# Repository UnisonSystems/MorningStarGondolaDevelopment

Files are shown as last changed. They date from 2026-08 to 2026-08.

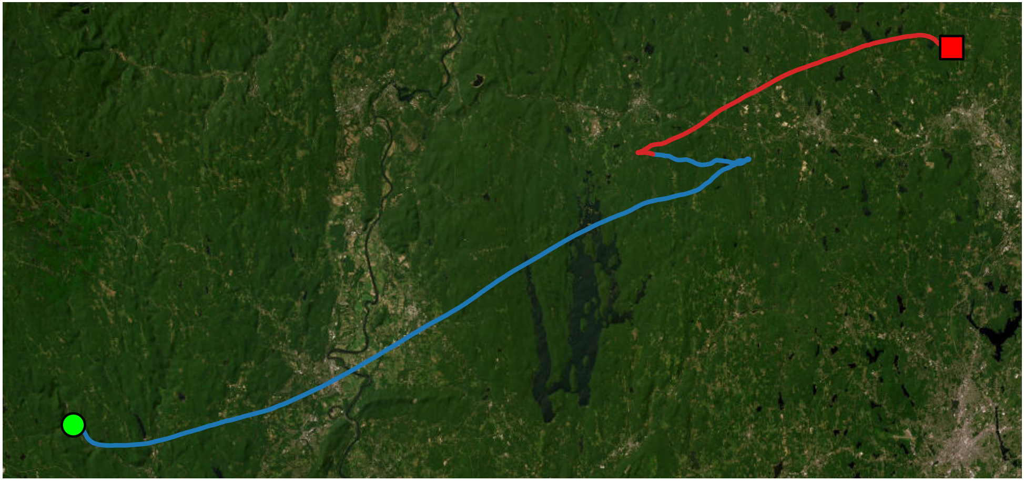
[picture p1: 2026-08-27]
Analysis/Flight/Report/trajectory_snapshot.png

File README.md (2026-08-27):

# Morning Star Gondola Development

Avionics, mechanical parts, bench tests, and post-flight analysis for the Morning Star high-altitude balloon gondola.

Current flight computer: Raspberry Pi Pico (RP2040) running the Earle Philhower Arduino-Pico core. Radio is a Tiny4FSK + Shield on a dedicated I2C bus. This repository does **not** contain Tiny4FSK firmware.

License: MIT (see `LICENSE`). Copyright 2026 Unison Systems.

## Layout

| Path | What it is |
|---|---|
| [`Flight-Software/`](Flight-Software/) | **Prototype Pico flight software.** Untested. Experiment with this. |
| [`Flight-Software-Heritage/`](Flight-Software-Heritage/) | MIT-Pico.ino flew in 2026. Also includes test scripts for novel sensors.|
| [`Benchtop-Testing/`](Benchtop-Testing/) | Single-sensor and combined Arduino sketches used to qualify hardware.|
| [`Analysis/`](Analysis/) | Python tools for flight logs and bench logs. Run generate_report.py on the cleaned flight log, DATALOG.CSV. Run test_main.ino to generate NNNN_flight_log.bin. Run bench_test_analysis.py with NNNN_flight_log.bin (try 0000_flight_log.bin as an example).|
| [`Hardware/`](Hardware/) | STL files for 3D-printed hardware. |

## Flight software

Source: [`Flight-Software/MIT-Pico/`](Flight-Software/MIT-Pico/).

Wiring and power: [`Flight-Software/pico_wiring.txt`](Flight-Software/pico_wiring.txt), [`Flight-Software/power_wiring.txt`](Flight-Software/power_wiring.txt).

| Item | Detail |
|---|---|
| Board | Raspberry Pi Pico |
| Core | Earle F. Philhower Arduino-Pico |
| Libraries | Adafruit BNO08x, Adafruit MAX31865, Adafruit SHT4x, Rob Tillaart MS5611, `SD` / `Wire` / `SPI` |
| On-board log | Packed binary records on MicroSD (`NNNN_flight_log.bin`) |
| Downlink | Pico is I2C peripheral `0x09` on GP2/GP3. Tiny4FSK is the controller and owns the 20 s packet cadence. |
| Run time | Until power loss or manual deactivation. GP10 MOSFET enable is asserted in `setup()` and held. |

Sensors logged to MicroSD:

- BNO086 at 100 Hz (SD only; not downlinked)
- MAX31865 + GY-63 MS5611 + SHT45 at 20 Hz
- XY-T01 #1 and #2 whenever a UART line parses (~1 Hz)

I2C snapshot to Tiny4FSK (16 bytes, little-endian): MAX temp, SHT45 temp, MS5611 temp, XY-T01 #1 temp, XY-T01 #2 temp, SHT45 RH, MS5611 pressure.

Open the `MIT-Pico` folder as an Arduino sketch (folder name must match `MIT-Pico.ino`). Build and flash with the Philhower Pico board package.

## Heritage firmware

[`Flight-Software-Heritage/`](Flight-Software-Heritage/) keeps the earlier payload software:

- `MIT-Onsite-Test/MIT-Pico` — Pico sketch from the CNT-era flight (LMP91000 array + Tiny4FSK slave)
- `MIT-Onsite-Test/i2c-scan` — I2C bus scanner
- `RaspPi Pico` / `RaspPi ZeroW` — MicroPython loggers from earlier gondola revisions

These are reference only. Pin maps and sensor lists do not match the current airframe.

## Bench tests

[`Benchtop-Testing/`](Benchtop-Testing/) is one sketch per check. Each `test_*` directory is its own Arduino sketch.

| Sketch | Purpose |
|---|---|
| `test_BNO086` | BNO086 on I2C0 |
| `test_GY63MS5611` | MS5611 |
| `test_MAX31865` | MAX31865 RTD |
| `test_SHT45` | SHT45 |
| `test_XYT01` | XY-T01 UART + heater commands |
| `test_MicroSD` | ADA254 card |
| `test_*_x_MicroSD` | That sensor plus SD logging |
| `test_main` | Combined logger used as the behavioral spec for current flight software |

## Analysis

- [`Analysis/Flight/`](Analysis/Flight/) — flight-log report generation (`generate-report.py`)
- [`Analysis/Testing/`](Analysis/Testing/) — bench-log helper (`bench_test_analysis.py`)

Use a virtualenv and the `requirements.txt` next to the flight script.

## Hardware

[`Hardware/`](Hardware/) is printable flight structure: Pico / sensor receivers, Tiny4FSK receivers, battery box, GoPro bay, switch housing, CNT cage (heritage), M3 washers.

## What this repo is not

- Not Tiny4FSK / Horus encoder source
- Not GoPro firmware
- Not a place to commit MicroSD flight binaries or USB-serial captures (see `.gitignore`)

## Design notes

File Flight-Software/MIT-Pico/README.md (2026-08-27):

# MIT-Pico

Board: Raspberry Pi Pico (RP2040)
Core: Earle F. Philhower Arduino-Pico

Libraries:
- Wire.h
- SPI.h
- SD.h
- Adafruit_BNO08x.h
- Adafruit_MAX31865.h
- Adafruit_SHT4x.h
- MS5611.h (Rob Tillaart)

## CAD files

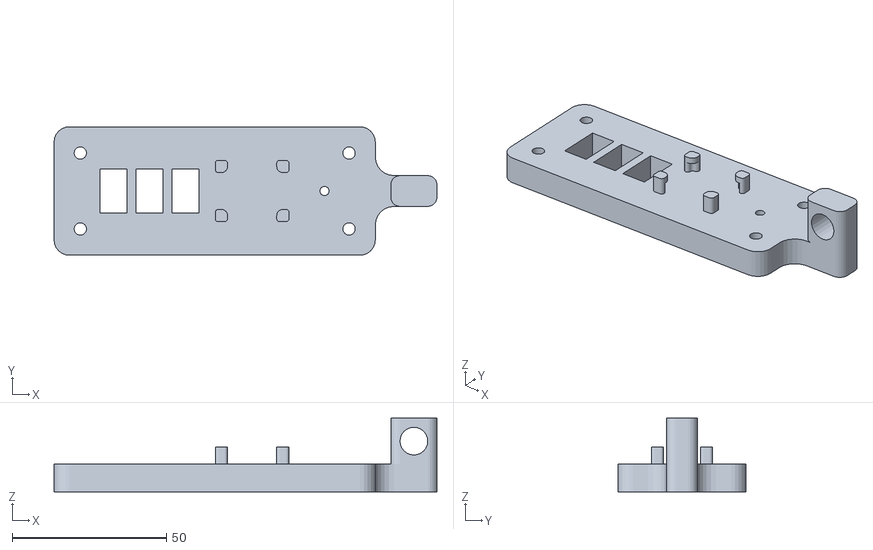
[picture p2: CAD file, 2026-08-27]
Hardware/switch_receiver.stl
124.3 x 41.7 x 24.0

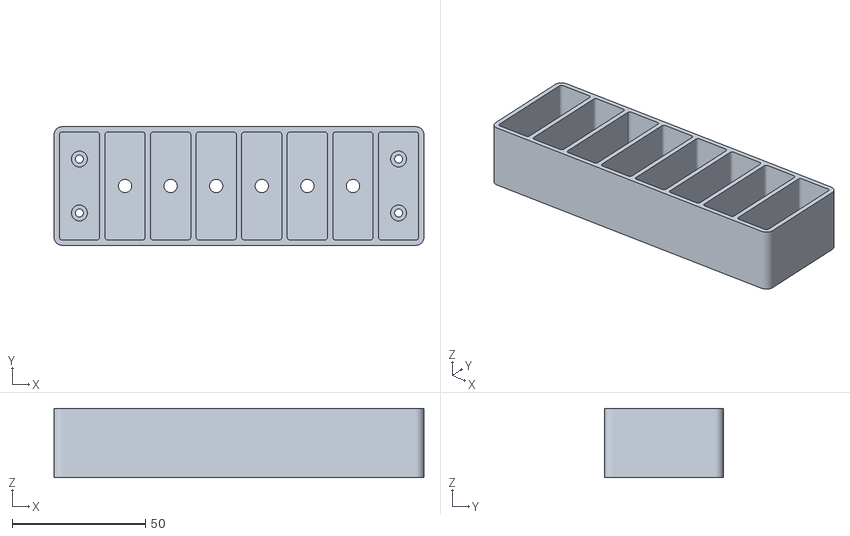
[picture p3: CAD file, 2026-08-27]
Hardware/Receiver_PCT-218.stl
138.8 x 44.5 x 26.0

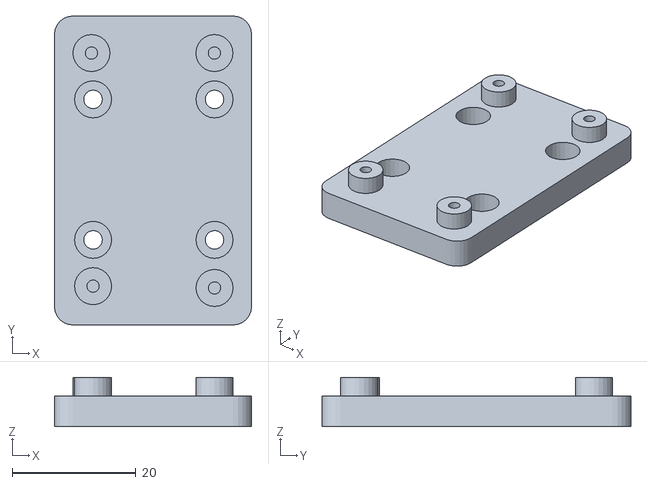
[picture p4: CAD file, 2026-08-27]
Hardware/Receiver_SD-Card.stl
31.9 x 50.0 x 8.00

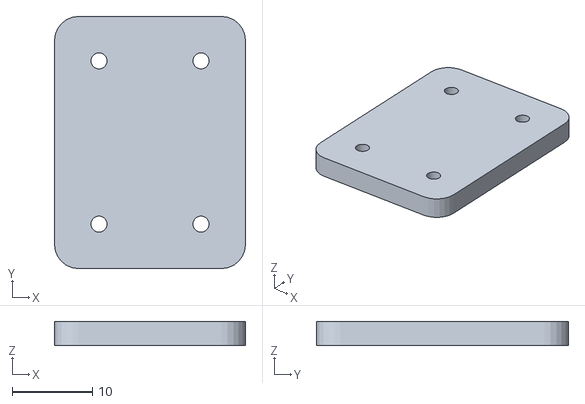
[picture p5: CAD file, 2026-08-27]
Hardware/Receiver_SHT45.stl
23.8 x 31.4 x 3.00

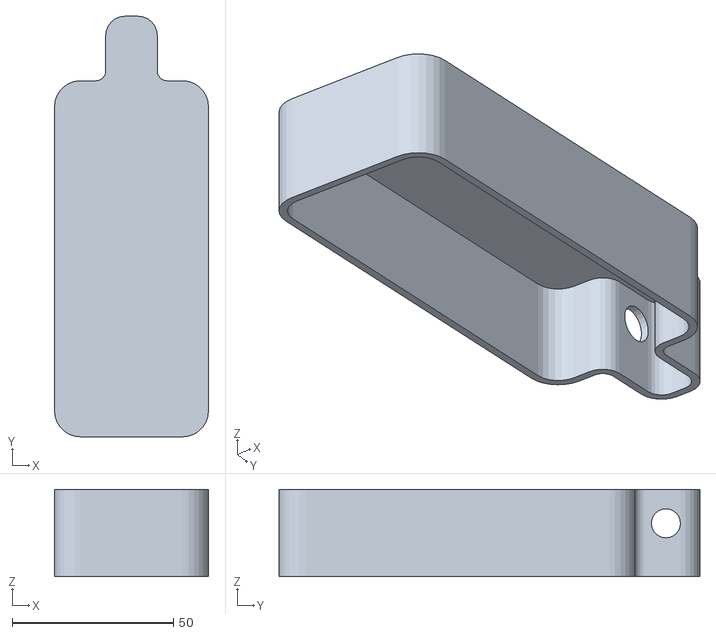
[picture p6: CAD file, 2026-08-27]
Hardware/switch_receiver_cover.stl
47.7 x 130.3 x 27.0

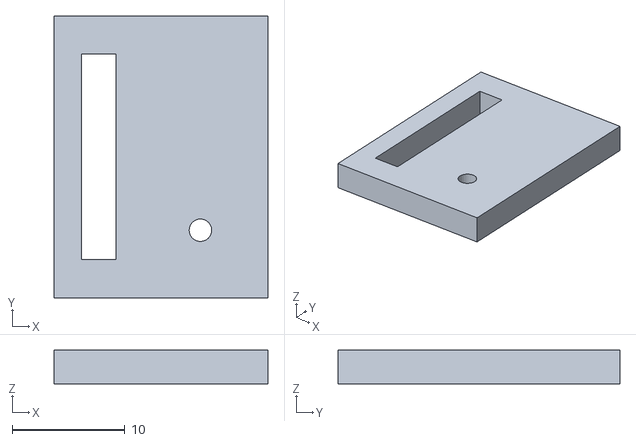
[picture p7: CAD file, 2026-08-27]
Hardware/Receiver_GY-63.stl
19.0 x 25.0 x 3.00

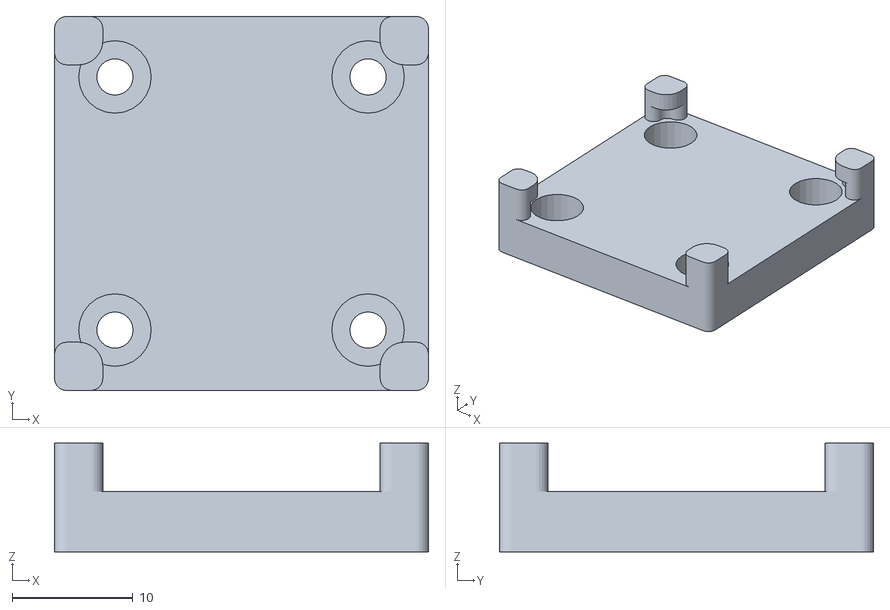
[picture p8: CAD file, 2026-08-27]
Hardware/Receiver_ICM-20948.stl
30.9 x 30.9 x 9.00

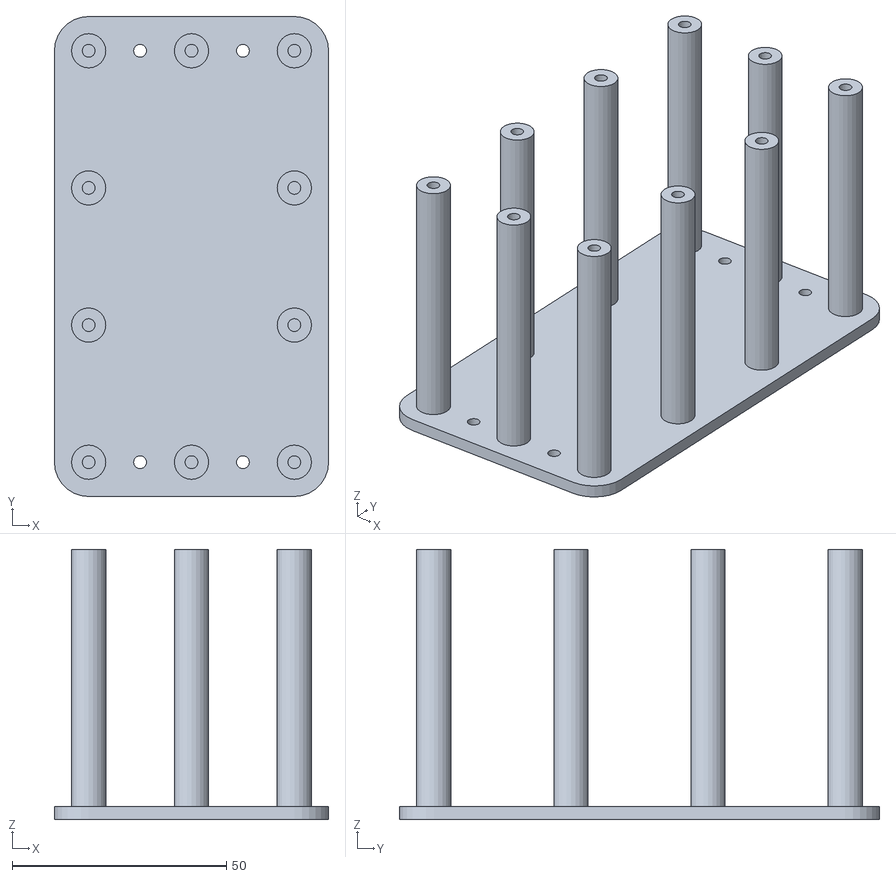
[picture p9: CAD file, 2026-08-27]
Hardware/CNT_electronics_cage.stl
64.0 x 112.0 x 63.0

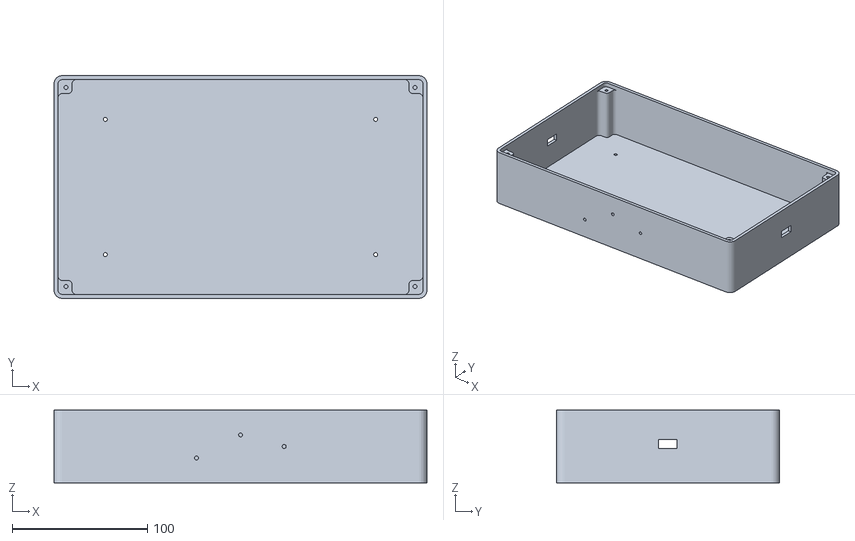
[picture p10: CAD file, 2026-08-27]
Hardware/battery_box.stl
275.8 x 164.8 x 53.8

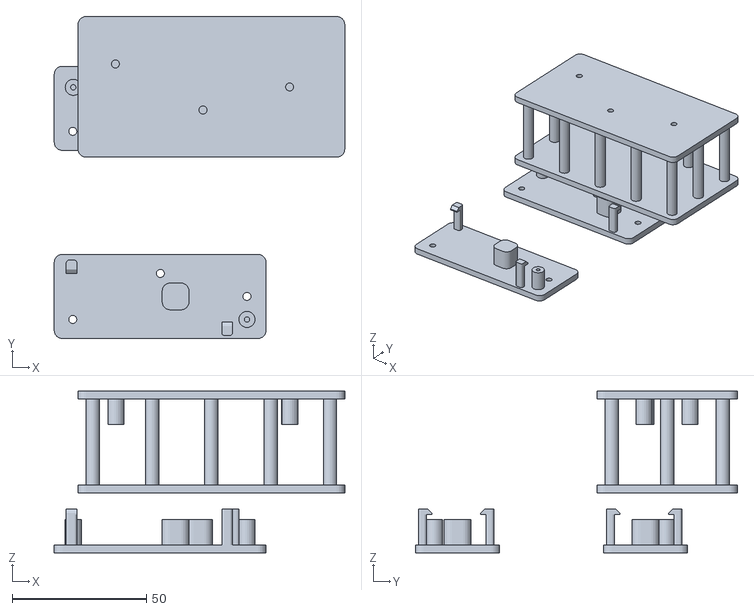
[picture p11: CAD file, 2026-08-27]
Hardware/Receivers_FSK.stl
108.1 x 119.8 x 60.3

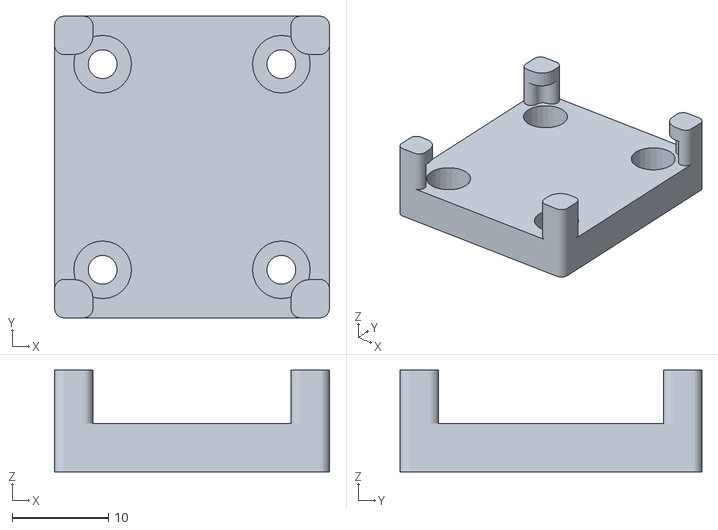
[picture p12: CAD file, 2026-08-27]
Hardware/Receiver_MAX31865.stl
28.6 x 31.4 x 10.6

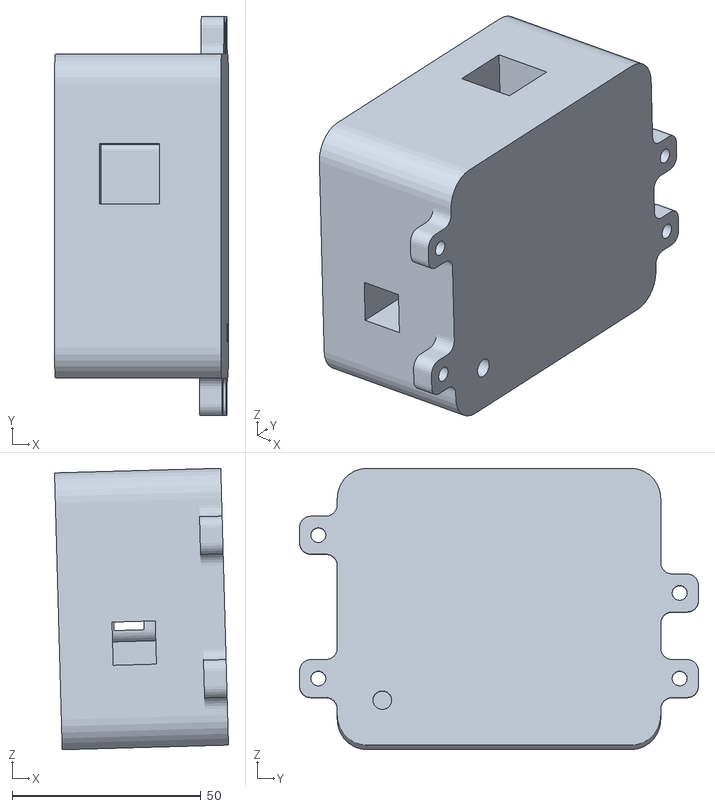
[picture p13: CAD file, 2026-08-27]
Hardware/GoPro_Bay.stl
46.1 x 105.8 x 74.6

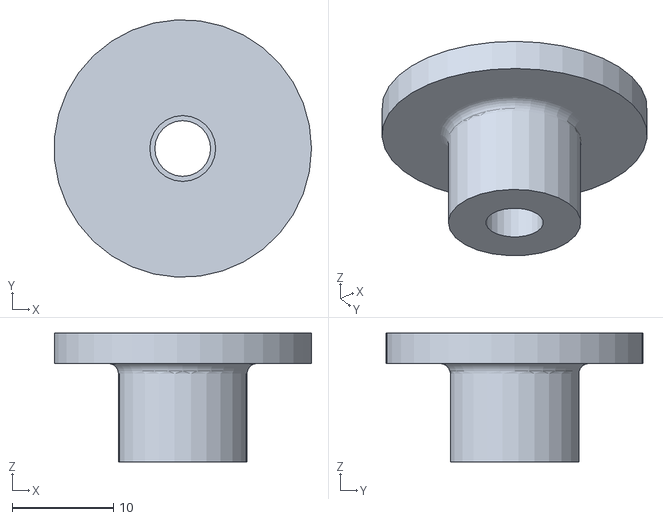
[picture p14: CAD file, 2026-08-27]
Hardware/Receiver_RTD.stl
25.3 x 25.4 x 12.7

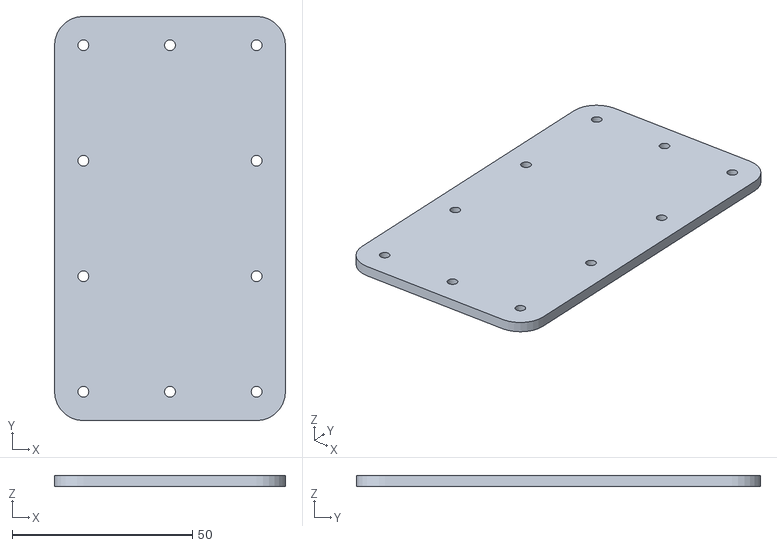
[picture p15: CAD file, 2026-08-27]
Hardware/CNT_electronics_cage_cover.stl
64.0 x 112.0 x 3.00

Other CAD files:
Hardware/Receiver_Pico.stl
Hardware/Receiver_HP.stl
Hardware/Receiver_XY-T01.stl
Hardware/Washer_M3.stl

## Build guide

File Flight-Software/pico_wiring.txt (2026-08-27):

| Pico Pin | Terminal Block | Function | Connected Devices |
|---|---|---|---|
| MicroUSB | — | Power input | Battery POSA (via rocker) + GND |
| VBUS | TB-5V | 5 V distribution rail | MS5611, MAX31865, MicroSD (ADA254), BSS138 HV, etc.  |
| GND | TB-GND | Common ground | All grounds, M_GPIO-, level shifter GND |
| 3V3(OUT) | TB-3V3 | 3.3 V rail | BNO086, SHT45, level shifter LV |
| GP0 (UART0 TX) | — | XY-T01 #1 TX (via LV) | BSS138 → XY-T01-1 RX |
| GP1 (UART0 RX) | — | XY-T01 #1 RX (via LV) | BSS138 → XY-T01-1 TX |
| GP2 (I2C1 SDA) | — | Tiny4FSK dedicated SDA | Shield SDA (Pico = slave 0x09) |
| GP3 (I2C1 SCL) | — | Tiny4FSK dedicated SCL | Shield SCL |
| GP4 (I2C0 SDA) | TB-SDA | Shared I2C SDA | MS5611, BNO086, SHT45 |
| GP5 (I2C0 SCL) | TB-SCL | Shared I2C SCL | MS5611, BNO086, SHT45 |
| GP6 | — | BNO086 INT | BNO086 INT (active-low) |
| GP7 | — | BNO086 RST | BNO086 RST (active-low) |
| GP8 (UART1 TX) | — | XY-T01 #2 TX (via LV) | BSS138 → XY-T01-2 RX |
| GP9 (UART1 RX) | — | XY-T01 #2 RX (via LV) | BSS138 → XY-T01-2 TX |
| GP10 | — | MOSFET control | M_GPIO+ |
| GP15 | – | Status indicator | LED |
| GP16 (SPI0 RX) | TB-MISO | SPI0 MISO | MAX31865 SDO, MicroSD (ADA254) MISO/DO |
| GP17 | — | MicroSD CS | MicroSD (ADA254) CS |
| GP18 (SPI0 SCK) | TB-SCK | SPI0 SCK | MAX31865 SCK, MicroSD (ADA254) SCK/CLK |
| GP19 (SPI0 TX) | TB-MOSI | SPI0 MOSI | MAX31865 SDI, MicroSD (ADA254) MOSI/DI |
| GP20 | — | MAX31865 CS | MAX31865 CS |

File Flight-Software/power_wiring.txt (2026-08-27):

Quick notes on notation:

I assign the names POS<A/B> and NEG<A/B> to the positive and negative lines of Outputs A/B.
The MOSFET has 4 screw terminals: M_IN+ (power supply positive line in); M_IN- (power supply negative line in); M_OUT+ (load positive line out); M_OUT- (load negative line out). The MOSFET has 2 GPIO pins: M_GPIO+ (the logic pin); and M_GPIO- (ground).
I refer to the ith terminal of terminal block receiving positive lines as T+<i>. I refer to the ith terminal of terminal block receiving negative lines as T-<i>.
I refer to an arbitrary lead of the ith FG26X7R1E106KRT00 as CAP_<i>A. I refer to other lead of the ith FG26X7R1E106KRT00 as CAP_<i>B.

The Battery supplies 5 V.

DD0324PW-1 and DD0324PW-2 output at 12 V.
 
Battery POSA connects directly to either rocker-switch terminal. Battery POSA (new wire) feeds out of the other rocker-switch terminal and connects to the MicroUSB port on the Pico. Battery NEGA connects directly to Pico GND.
 
Battery POSB connects directly to M_IN+. Battery NEGB connects directly to M_IN-. M_OUT+ connects to T+0.
 
T+1 connects to CAP_1A and then Shield VIN. Shield GND connects to CAP_1B and then T-1.
 
T+2 connects to CAP_2A and then DD0324PW-1-IN+. DD0324PW-1-OUT+ connects to XY-T01-1-VIN. XY-T01-1-GND connects to DD0324PW-1-OUT-. DD0324PW-1-IN- connects to CAP_2B and then T-2.
 
T+3 connects to CAP_3A and then DD0324PW-2-IN+. DD0324PW2-OUT+ connects to XY-T01-2-VIN. XY-T01-2-GND connects to DD0324PW-2-OUT-. DD0324PW-2-IN- connects to CAP_3B and then T-3.

T+4 connects to GoPro VIN (via USB-C). GoPro- connects to T-4.

T-0 connects to M_OUT-.
 
Pico GP<X> connects to M_GPIO+. M_GPIO- connects to Pico GND.

Pico VBUS connects to TB-5V.

Balloon Type  |   Diameter at Release (m)
----------------------------------------------------
HAB-350       |    0.125
HAB-350       |    
HAB-350       |    
HAB-350       |    
HAB-350       |    
HAB-350       |    

37.6
110
26.8

T-plug 13.3 x 7.6
T-plug wires: 4 x 8
4-pin connector: 14.74 x 8.35

Battery base to port hole: 120

Really need to address STTR proposal
Need to check Ambitus
Need to check Data Annotation
Handover Doc
Balloon Trajectory Tool
Gondola:
	- Pressure sensor
	- Assembly
	- Test

1:53 PM EST
6:53 PM UTC
42.278795, -72.975588

-55.85-7.2

I'm designing a trajectory-prediction tool for high-altitude balloons (HAB). I'm starting from first principles where possible. For example, from Newton II, we have
$$F = m\vec{a} = (\rho_{\text{atm}}V - m)g\hat z - \frac{1}{2}\rho_{\text{atm}}C_DA|\vec{v}-\vec{u}|(\vec{v}-\vec{u})$$
Going through the right-hand side term-by-term...
$\rho_{\text{atm}}$, the atmospheric density, is well known as a function of altitude.
$V$, the balloon volume, is more difficult to predict, since it is driven by the pressure differential across the inflated balloon envelope, which subsequently depends on (1) the total amount of lifting gas in the balloon and (2) the elastic properties of the envelope—both quantities which are not easy to obtain.
$m$, the total system mass, is easier than $V$, but still presents difficulties. In real-world applications, $m$ is a composite of masses (e.g., payload(s), rigging, balloon envelope, lifting gas). As with $V$, the mass of the lifting gas is not easily obtained.
$g$ is the gravitational acceleration, which is extremely well known, and constant for all intents and purposes in the context of HABs.
$C_D$ is a bit hand-wavy, but probably use 0.25–0.3.
$A$, the reference area, is just $V$ with some extra stuff. Assuming a spherical balloon, $V = \frac{4}{3}\pi R^3\rightarrow R = \left[\frac{3V}{4\pi}\right]^{1/3}$, and $A = \pi R^2$. So, if you solve the $V$ problem, $A$ is likewise solved.
$\vec{v}$ is the velocity of the balloon. This velocity (and, necessarily, its magnitude) will come from integration of $\vec{a}$.
$\vec{u}$ is the local wind velocity (local implies "arbitrary point"). The atmosphere is extremely dynamic/chaotic and, of course, spans the entire planet up to hundreds of km. We rely on NOAA tools for this.
Thoughts?

NIAC Phase II announcements expected November 30, 2026.

Michael Hect (scanning microscope) didn't tell Sara that his scope didn't work

Sara talked to Arpita: MIT won't move gift money without permission. She's fine with moving the money. The sponsors are not happy because we haven't launched.

I have a gondola for high-altitude ballooning. I'd like to do some thermal testing relevant to the mission environment. I've tested the gondola in a meat freezer at approximately -17 ºC, but I'll need dry ice to reach mission-relevant conditions, which can reach roughly -60 ºC. I'm thinking about how to set up this experiment (1) safely and (2) in a manner that yields roughly uniform temperature on all external surfaces of the gondola. It's fine that the ice will be at around -80 ºC instead of -60 ºC. The gondola is only around 15.75 in. wide x 13.5 in. long x 10 in. high, so I can fit it in a freezer, tote, box, or large cooler. But we should avoid conduction from the dry ice. Any thoughts on this?

Schmidt partnership regarding AI?

MS Word: Proprietary + Commercial (OR)
LaTeX/Overleaf: Open-Source (OR)
Google Docs: Proprietary + Commercial (OR)
Etc.

Check about Zoom or similar for in-person, synchronous portion
Check about YouTube or similar for online/asynchronous portion

Identify which activities can continue without connectivity or access to the affected technology, should the instructional materials or methods be available and/or modified to accommodate the achievement of the learning objectives and intended learner experience. If you have immersive technology and the hardware is unavailable or the Government elects not to procure or maintain it, please call out how that specific section would be impacted. 

The Government is assessing your risk mitigation if technology fails. Map the intended activity to its offline alternative."

Low Power
Amenable to Ruggedization
Task Handling

Note that WiFi for pre-flight configuration is 100% unnecessary when the device has a built-in transmitter for downlink.

So, the STM32L4 wins on the following basis:
1. The STM32L4 is the most power-efficient and rugged MCU under consideration.
2. The STM32L4's task isolation is only outperformed by the ESP32 and ESP32-S3, which are significantly less power efficient and rugged; similar on almost all other metrics; and only significantly outperform the STM32L4 on the quality of their toolchain & ecosystem.
3. The STM32L4's SRAM + Flash is only marginally outperformed by the ESP32-S3 and Teensy 4.x. The ESP32-S3 is a strong contender, but the Teensy is just too hungry.
4. The STM32L4's peripheral hardware + DMA is matched but not exceeded by the ESP32-S3, STM32F4, and Teensy 4.x. As stated in (3), the ESP32-S3 is a strong contender, but the STM32F4 and Teensy 4.x are quite hungry.
5. The only contender which surpasses the STM32L4 in toolchain & ecosystem is the ESP32-S3, which does so comfortably and is a legitimate contender.
6. The STM32L4 is unsurpassed by any legitimate contender when it comes to real-time/timing.
7. The STM32L4 is marginally better than any legitimate contender when it comes to power-supply robustness.

Even under the current weighted rules, the STM32L4 beats the ESP32-S3 by a point. Now, if we relax the ruggedization metric (the least important metric, due to the accommodative capacity of the gondola) to 0.5, the ESP32-S3 ties the STM32L4. In this case, the STM32L4 comfortably outperforms the ESP32-S3 in power efficiency, but the ESP32-S3 comfortably outperforms the STM32L4 in toolchain & ecosystem; all other metrics differ marginally.

We could consider a heretofore unmentioned metric: cost.

For what it's worth, the STM32L4 is meaningfully more expensive than the ESP32 (STM32L486QGI6 is listed at $10.04/unit vs. 356-ESP32-S3 at $1.85 on Mouser).

Based on our discussion thus far, the relevant question appears to be whether the power-efficiency performance difference between the STM32L4 and ESP32-S3 justifies the 5x price gap.

Check out this power table for a generic mission:

The primary payload changes per flight, so we assume a hungry element relative to other non-camera peripherals. Neglecting the GoPro Max, which is obviously in a league of its own with respect to power demand, the Pico ties the ADA254 as the most power-hungry element. Suppose we swapped out the RP2040 for an STM32L4 and an ESP32-S3 (disregarding the compatibility issues). What would these subs to the Pico's power consumption? This exercise could give me a concrete feel of exactly what the STM32L4 delivers (or doesn't) over the ESP32-S3.

MAX-M10M-00B
MAX-M10M-20B
MAX-M10N-00B
MAX-M10N-10B
MAX-M10S-00B

MCU: STM32L476RGT3
GPS: u-blox MAX-M10N-10B
Radio: Semtech SX1262
Balloon antenna: Half-wave dipole, vertical polarization
TPH: MS5611 (Pressure + Temperature) and SHT45 (Relative Humidity + Temperature); SHT45 superior for temperature
40 GPIO pins (copy Pico architecture)
MicroUSB (flash + optional power input)

Ground station antenna: Yagi, ~8 dBi, vertical polarization, fixed/occasional pointing on chase vehicle

Outstanding tasks:
GPIO count (to be workshopped)
MicroSD interface
Power architecture (battery input, regulation, monitoring, etc.)
SX1262 RF matching network + harmonic filtering
SX1262 TCXO
Antenna connector (U.FL / SMA / other)
Status LEDs / basic indicators
GPS backup power (battery or supercap)

Comment
Double the hungriest non-camera device. Assume penalty.
Datasheet max (active + bias)
Datasheet active current
Conservative continuous sensing (>> datasheet)
Static MOSFET level-shifter
High-end fusion mode
Continuous heavy SD logging (below regulator max)
Module + LCD + active relay
Elevated max-load + peripherals
High-end continuous recording
2 hours + 30% margin
30% margin

Is it true that one would need to be disciplined about pin multiplexing (SPI, I2C, UART, SDMMC, etc.)? My understanding is that the LQFP-64 package is already relatively pin-constrained once power, crystal, reset, boot, SWD, and RF-related pins are accounted for (yes, I'm assuming GNSS and SX1262 onboard).

% \usepackage[table,xcdraw]{xcolor}
% Beamer presentation requires \usepackage{colortbl} instead of \usepackage[table,xcdraw]{xcolor}
% \usepackage{tabularx}   % <-- added for wrapping columns
% \usepackage{array}      % <-- usually loaded by tabularx; needed for the >{...} modifiers

GENNEL: 7 g

138.8*44.5 + 44.5*36.2

78 cm2

5 * 7 * 0.1 * 1.83

6.3875

HOOVO 2S Lipo Battery 7.6V 9000mAh 120C RC Battery Hard Case EC5 Plug 2Pack

I found this LiPo pack on Amazon: "11.1V Lipo Battery 3S 5200mAh 80C Lipos Hard Case with XT60 Connector" by EMEPOVGY Store. Suppose I want to use this with a step-down converter as a stand-in for my 5 V source. By our earlier reasoning, the *energy* stored in the battery is
$   Wh = 5.2\times 11.1 = 57.72   $
If we convert to 5 V, then the equivalent capacity (before losses) is
$   57.72\div 5 = 11.544\text{ Ah}   $
or 11544 mAh. Assuming 80% efficiency, this translates to 9235.2 mAh. Do you agree with this reasoning?

C*11.1/5

0.8*7.6/5

eta*C*V_nominal/V_out

0.8 * 7600 * 11.1 / 5

164.4 - 49.9 

12.743 - 132.848

120.105

133 - 12.6 =120.4 

NASA-STD-8739.4

https://standards.nasa.gov/sites/default/files/standards/NASA/A/4/nasa-std-87394a_w_change_4_0.pdf

Okay, I've done a short writeup on the problem. 

Funktion

1. SPI (Serial Peripheral Interface) is a synchronous, full-duplex serial communication protocol commonly used for short-distance communication between a microcontroller (or other master device) and peripheral devices such as sensors, displays, memory chips, and ADCs.
	1. What does "synchronous" mean in this context? You answered this later: "A shared clock signal keeps both sides in lockstep. There is no start/stop bit overhead like UART." However, I'm still unsure:
		1. Among whom is the clock signal shared?
		2. What does it mean for "both sides" to be "in lockstep"?
	2. What does "full-duplex" mean in this context? You answered this later: "Data can be sent and received at the same time."
	3. What constitutes "short-distance"?
2. Master-slave architecture: One master controls the bus and generates the clock. One or more slaves respond.
	1. What is the "bus"?
	2. What does it mean to "generate the clock", and why is this relevant?
3. No addressing: Devices are selected by dedicated chip-select lines rather than by address bytes.
	1. To "select" a device X basically means the master says "I am going to communicate with X and only X", yes?
	2. A dedicated chip-select line is a physical line connecting master to slave?
4. SCLK (Serial Clock):
	1. "Clock generated by the master." See 2.2.
	2. "Data is shifted on clock edges."
		1. What does it mean to "shift data"?
		2. What is a "clock edge"?
	3. Are there other abbreviations for the SCLK pin?
5. MOSI (Master Out, Slave In):
	1. In what manner does data exist on the physical MOSI line?
6. MISO (Master In, Slave Out):
	1. In what manner does data exist on the physical MISO line?
7. SS / CS (Slave Select / Chip Select):
	1. "Active-low" means a chip is selected when the voltage drop between CS and GND is 0?
	2. What does it mean to put its MISO line in high impedance?
	3. Are there other abbreviations for the CS pin?
8. Some devices support a 3-wire mode (shared MOSI/MISO), but classic SPI is 4-wire.
	1. Intuitively, a 3-wire mode would disable synchronous capability. Is this correct?
9. The master starts generating clock pulses on SCLK.
	1. Characterize the clock pulses generated by the master on SCLK:
		1. Is this signal identical in all cases for all hardware?
		2. If the answer to 9.1.1 is "No", answer the following question with characteristic ranges where necessary:
			1. What is the period?
			2. What is the amplitude?
			3. What is the shape?
10. On each clock edge (depending on mode), both sides shift one bit...
	1. A "clock edge" is not a physical thing. What does "on each clock edge" mean in this context?
	2. "both sides shift one bit": See 4.2.1. 
11. The master/slave simultaneously shifts a bit out on MOSI/MISO.
	1. In my mental model, a given 1 or 0 became a 1 or 0 at a specific place and time, and in response to a specific event. If this is even remotely true...
		1. From where do these bits originate?
		2. What event triggers their generation?
12. "Because the shift registers on the master and slave are connected in a loop during the transfer..."
	1. What is a shift register?
	2. What does it mean for the shift registers to be "connected in a loop"?
13. "...every clock cycle exchanges one bit in each direction."
	1. The usage of "clock cycle" as opposed to "unit of time" or similar seems to imply that these terms are analogous but not identical. That is, if the clock doesn't cycle, bits are not exchanged, regardless of the passage of time; in this sense, clock cycles represent simulated time. Is this correct?
14. "If the master only wants to read data, it still must send dummy bytes (often 0x00 or 0xFF) so that the clock keeps running and the slave can shift data out."
	1. This appears to be new information. This statement implies that the master does not have direct control over SCLK, but rather, indirect control via MOSI. Otherwise, the master could just "keep the clock running" without sending anything, correct?
15. "Data is almost always transferred MSB first, though some devices allow LSB-first configuration."
	1. What is MSB?
	2. What is LSB?
16. "CPOL (Clock Polarity): Idle state of the clock"
	1. What does it mean for the clock to idle?
17. "Which edge is used for sampling vs. shifting"
	1. What is "sampling" in this context?
	2. See 4.2.1.
18. "Both the master and the slave must be configured for the same mode."
	1. Are devices always/ever configurable?
	2. How does one know the mode to which a given device is configured?
19. Confirm that data received through a MISO/MOSI daisy chain cannot be attributed to a specific sensor (i.e., that data origin is lost in this architecture).
20. "Very high speed possible"
	1. Relative to what?
21. "Full-duplex" is a strength because additional information transfer is not required to initiate and terminate communications?
22. "Extremely simple hardware and software."
	1. Compared to what?
23: "No bus arbitration or addressing overhead."
	1. What is bus arbitration?
	2. Addressing is resolved by CS?
24: "Requires more pins than I2C"
	1. Evaluate my current understanding:
		1. 4 pins are required for communication with one device, unless MISO/MOSI share a wire at the expense of synchronicity.
		2. The number of required pins increases by 1 (CS) per device, (a) unless devices are daisy chained at the expense of slave onymity or (b) a mux is inserted between master and slaves.
25: "No acknowledgment or built-in error detection."
	1. What is "acknowledgement" in this context?
26: "Limited to short distances"
	1. Output a rule-of-thumb prohibitive distance (i.e., a distance ceiling) for SPI
27: "Only one master is practical in the classic implementation."
	1. Why?
	2. Give an example, if you can, of a scenario in which multiple masters would be beneficial.
	3. The clause "in the classic implementation" implies that SPI can be implemented in such a way that multiple masters become practical. Is this true?
28: "SPI is frequently used with high-speed or low-latency peripherals (IMUs, high-resolution ADCs, flash memory, displays, some pressure and environmental sensors). Many modern sensors support both SPI and I2C; SPI is preferred when higher throughput or lower latency is needed, or when the I2C bus is already busy."
	1. Contrast the terms "high-speed", "low-latency", and "high-throughput".
	2. Your response implies that I2C is the primary competitor with SPI. Is this accurate?

Awesome. We made a ton of headway there. Follow-up response:
1. "Your note swapped the two definitions.": Correct. That was a typo. This is resolved.
2. "3-wire mode": My "synchronous capability" comment was a propagation of the duplex/synchronous flip error. I should have said "Intuitively, a 3-wire mode would disable full-duplex capability." You confirmed this in your response (the link becomes half-duplex), so this is resolved.
3. "The two registers therefore form a single circulating path—a loop—of bits." For something useful to happen, transferred information must *exit* that loop. How does that happen?
4. Regarding "dummy bytes"...
	1. You said "almost all microcontroller SPI hardware peripherals are designed so that clock edges are generated only while a data word is being shifted out of the transmit register." What is an "SPI hardware peripheral"? Could this be, for example, a sensor whose data is being transmitted over SPI, or is this something that exists as part of the SPI framework (independent of the data generator)?
	2. You said "[t]he dummy write is an artifact of how the peripheral is implemented..." What does "how the peripheral is implemented" mean?

Larry Graham – Sly & the Family Stone
Bootsy Collins – Parliament-Funkadelic
Victor Wooten

(1198 - 698)/2

X→S

Smartmiao SZ

Note: It is recommended to use a current of less than 2.5A for long-term operation, and add a heat sink (output above 10W); Since it is a boost module, in order to ensure stable output, please maintain a minimum voltage difference of 1.5V

"If the master only wants to read data, it still must send dummy bytes (often 0x00 or 0xFF) so that the clock keeps running and the slave can shift data out."
    1. This appears to be new information. This statement implies that the master does not have direct control over SCLK, but rather, indirect control via MOSI. Otherwise, the master could just "keep the clock running" without sending anything, correct?

min(f_{\text{sck,m}, f_{\text{sck,m}}

LMP91000EVM
CQRobot MCP23017 16-bit I/O Expander Module
Electrocookie Solderable Breadboard PCB
CD74HC4067 CMOS 16 Channel Digital Analog Multiplexer
12 chemiresistors (each takes one wire in + one wire out)

Cross-reactive sensor arrays
Differential sensing

I have a flight log called DATALOG.CSV in my working directory. I need to create a Python script that generates a comprehensive flight report, "Flight_Report.pdf" containing the following plots:
Page 1:
1. Altitude vs. Time
Page 2:
1. Temperature vs. Time
2. Altitude vs. Temperature
Page 3:
1. Pressure vs. Time
2. Altitude vs. Pressure
Page 4:
1. Humidity vs. Time
2. Altitude vs. Humidity
Page 5:
1. Speed vs. Time
2. Altitude vs. Speed
Page 6:
1. Ascent Rate vs. Time
2. Altitude vs. Ascent Rate
Page 7:
1. Flight path 2D (see mapper2.py attached)
2. Link to Google Earth + explanation (see mapper3d_2.py attached, which generates a proto-Flight_Report.pdf)

Columns in DATALOG.CSV: <quantity> (<units>): <column number>
Lat (degrees x 10^5): 3
Long (degrees x 10^5): 4
Altitude (m above sea level): 8
Temperature (deg C): 12
Pressure (mbar): 13
Humidity (RH%): 21
Speed (m/s): 10
Hours: 5
Minutes: 6
Seconds: 7

Note that time must be constructed:
1. Define t0 =  (first-row hours)*60 + (first-row minutes) + (first-row seconds)/60
2. For any row, the time is hours*60 + minutes + seconds/60 - t0

Plot specifics:
1. No titles
2. Label axes as <quantity> (<units>)
3. Don't allow x-increments or y-increments to become excessively large, but also don't flood the plots with ticks.
4. For the 2D flight path, include no title, no axis labels---nothing but the image.
5. Note that the 3D trajectory does not get plotted in the PDF. We just create the KMZ, link the user to Google Earth, and explain how to upload/interact with the trajectory.

If you need more information in order to generate the script, let me know what you need before attempting a solution. Otherwise, have at it.

Title: How to Launch a High Altitude Balloon
Author: Habtronics
Last Updated: July 2026
Link: https://docs.google.com/document/d/e/2PACX-1vTHzam3NZknYssoTlnVG-I9p8UfS4e-8QlCTdtmzxdHeih_sm_SeeOmOQjUd_ksp9qEUEnXfDMQA7ZZ/pub

Import file to map project
Upload from device

The plots are looking excellent. We're going to make an important modification, however. We wish to distinguish values measured during ascent from values measured during descent. The strategy is straightforward:
1. Identify the maximum value of altitude. The row containing this value divides the CSV into "ascent" and "descent" values.
2. Plot "ascent" values in blue. Plot "descent" values in red.

1. Heritage flight software (complete source code archive from OG project)
2. New stuff:
	a. Updated flight software
	b. Entirely new benchtop testing software
	c. Data analysis software for (a) and (c) 
3. STL files for 3D printed components

├

|__
├

├── Flight-Software/              # updated Arduino (C++) flight software

Need "0000_flight_log.bin" in Analysis/Testing/
Need Unison Systems' handover doc in Handover-Docs
Need full Flight-Software/

In code, we command the Pico to drive a PWM ramp on GP10 from 0\% → 100\% over roughly 300 ms (software soft-start), which delivers power to both MOSFET switches, subsequently connecting all loads to their respective batteries.

−32,768 to 32,767

0.03125

MAX31865 temp 
SHT45 temp
MS5611 temp
XY-T01 #1 temp
XY-T01 #2 temp
MS5611 pressure
SHT45 humidity.

(-80 to +60 deg C)

Exact new CSV / packet field order
After deleting every CNT* column, what is the precise ordered list of columns the downlink packet must supply (especially relative to the retained Callsign…Batt and the BME280 Temp/Pressure/Humidity that stay on the Tiny4FSK side)? Please give the full desired column order including the 7 new fields with the exact names you want in the CSV.

Callsign,Packet,Lat,Lon,Hours,Minutes,Seconds,Alt,AscentRate,Speed,Sats,Batt,T-BME280,T-MAX31865,T-SHT45,T-MS5611,T-XYT011,T-XYT012,P-BME280,P-MS5611,H-BME280,H-SHT45

Explicit mapping:
T-BME280: Temperature reported by the BME280
T-MAX31865: Temperature reported by the MAX31865
T-SHT45: Temperature reported by the SHT45
T-MS5611: Temperature reported by the MS5611
T-XYT011: Temperature reported by the XY-T01 #1
T-XYT012: Temperature reported by the XY-T01 #2
P-BME280: Pressure reported by the BME280
P-MS5611: Pressure reported by the GY-63 MS5611
H-BME280: Relative humidity reported by the BME280
H-SHT45: Relative humidity reported by the SHT45

SD logging scope
Implement the exact cooperative sampling rates, double-buffer (2×24 KB), binary packed records (BnoRecord / SuiteRecord / XyRecord), global sequence, flush-on-80%-or-2 s, SPI bus recovery, and filename scheme from test_main.ino?
Duration: fixed 2 h (as in the test sketch), indefinite until power loss, or configurable?
Should the binary log also capture the values being offered for downlink, or strictly the high-rate science records (BNO only on SD)?

XY-T01 control policy
Keep the exact open-loop startup sequence from test_main.ino (S:100 for ~2 s → S:000 for 1 s → S:020 held for the rest of the flight) plus continuous non-blocking UART parsing, or implement closed-loop set-point control driven by the measured temperatures?

Additional telemetry / status in the I2C packet or logs
Any other values desired (Pico-side battery voltage via ADC, sensor health / fault flags, sequence numbers, free RAM, MOSFET state, etc.)?

Code organization & environment
Preference for multi-file modular structure (like the original MIT-Pico with pinout.h, sensor helpers, etc.) versus a cleaner single-sketch + helper-files style closer to test_main.ino? Any required Arduino-Pico core version, specific library versions (Adafruit BNO08x / MAX31865 / SHT4x, MS5611, etc.), or other constraints?

Power sequencing
Confirm that GP10 (MOSFET) is driven HIGH early in setup() to enable the 12 V rails for both XY-T01 heaters (and the Shield) and remains asserted for the entire flight. Any other power-up / power-down sequencing needed?

Regarding Q9: this is a very important question, as I omitted important information in my original prompt. First, to the question, yes: GP10 (MOSFET) is driven HIGH early in setup() to enable (1) the 12 V source for both XL6019s and (2) the 5V rail servicing the Shield, GoPro, and XY-T01s. After this, GP10 remains asserted for the entire flight. No other power-up / power-down sequencing needed *after the original power-up*. However, I should have stated the manner in which GP10 is to be driven on startup: In code, we command the Pico to drive a PWM ramp on GP10 from 0\% → 100\% over roughly 300 ms (software soft-start), which delivers power to both MOSFET switches, subsequently connecting all loads to their respective batteries. Any questions about this?

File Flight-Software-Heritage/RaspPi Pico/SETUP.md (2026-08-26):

# Setup — Headless 12-device chronoamperometry logger (Raspberry Pi Pico)

Holds 12 CNT-on-interdigitated-electrode devices at a constant +0.5 V and logs their
current once per second to CSV files on a microSD card. No screen, no GUI: it starts
on boot, blinks the onboard LED to show it is running, and writes crash-safely.

> **Which "Pico":** this is the **Raspberry Pi Pico** (RP2040 microcontroller running
> MicroPython), *not* the PalmSens EmStat Pico. If you were handed an EmStat Pico,
> none of this applies — that is a different instrument programmed in MethodSCRIPT.

This guide covers everything end to end: what you need, flashing MicroPython, getting
the scripts onto the board, wiring, a wiring self-test, running it, and viewing and
exporting the data.

---

## 1. What you need

**Hardware**
- Raspberry Pi Pico (standard RP2040 board)
- LMP91000EVM potentiostat front end (with its onboard ADC161S626)
- MCP23017 I²C GPIO expander
- CD74HC4067 16-channel analog multiplexer
- microSD card module (the common 5 V type with onboard regulator + level shifter)
- microSD card, formatted **FAT32** (≤ 32 GB works cleanly with the standard driver)
- **5 V USB powerbank** with a micro-USB cable to power the Pico (any standard USB
  powerbank — its output is 5 V). No boost converter is needed.
- Female–female jumper wires

**Software (on your computer)**
- [Thonny](https://thonny.org) — the easiest way to flash, copy files, and see output.
  (Command-line alternative: `mpremote`, installed with `pip install mpremote`.)
- The MicroPython firmware `.uf2` for the Raspberry Pi Pico, from
  https://micropython.org/download/RPI_PICO/

---

## 2. Wiring

The RP2040 has two I²C and two SPI peripherals. The ADC lives on **SPI0** and the SD
card on **SPI1**, so the two never contend. Pin numbers below match the `var.py` pin
map — change them in one place if you rewire.

### Digital connections to the Pico

| Signal | Pico GP (physical pin) | Connects to |
|---|---|---|
| I²C SDA | GP8 (pin 11) | LMP91000 SDA **and** MCP23017 SDA (shared bus) |
| I²C SCL | GP9 (pin 12) | LMP91000 SCL **and** MCP23017 SCL (shared bus) |
| ADC SCLK | GP18 (pin 24) | LMP91000EVM SCLK |
| ADC MOSI | GP19 (pin 25) | LMP91000EVM MOSI |
| ADC MISO | GP16 (pin 21) | LMP91000EVM MISO |
| ADC CS | GP17 (pin 22) | LMP91000EVM CS (was CE0 on the Pi) |
| SD SCLK | GP10 (pin 14) | SD module SCK |
| SD MOSI | GP11 (pin 15) | SD module MOSI |
| SD MISO | GP12 (pin 16) | SD module MISO |
| SD CS | GP13 (pin 17) | SD module CS |

### Power

The powerbank plugs into the Pico's **micro-USB** port. That puts the powerbank's 5 V
onto the Pico's **VBUS** pin, and the Pico regulates its own 3.3 V on the `3V3(OUT)` pin
— so both rails come from the one USB connection, with no boost converter.

- **Powerbank** → Pico **micro-USB** port.
- **Pico `VBUS`** (pin 40) → LMP91000EVM **5 V** pin (the ADC's analog supply)
  **and** the microSD module **VCC**.
- **Pico `3V3(OUT)`** (pin 36) → LMP91000 3.3 V, MCP23017 VCC, CD74HC4067 VCC.
- **Common GND** → tie every board's ground together (Pico GND, e.g. pin 38).

> **The one mistake that will silently break it:** the microSD module you have is the
> 5 V type — its onboard regulator needs ~5 V in. Powering its VCC from 3.3 V browns
> out the card and it will not mount. Its VCC must come from **VBUS (5 V)**. The SPI
> data lines are still 3.3 V from the Pico; only VCC is 5 V.

> **Note on VBUS:** it carries 5 V only while the micro-USB is powered (by the
> powerbank in the field, or by your computer while programming) — that's exactly when
> you need it. You won't have the powerbank and a computer on the port at once, and
> both supply the same 5 V, so nothing special is required when switching between them.

### Analog / electrode side (unchanged from the AIRBORNE build)

The mux common line goes to the LMP91000 working-electrode (TIA) input; the 12 device
return leads share the CE/RE bias node with the EVM's 2-WIRE jumper set. MCP Port A
bits 0–3 drive the CD74HC4067 address lines S0–S3, so device N maps to mux channel N.
This is identical to the Zero W hardware — if that was already built, leave it as is.

---

## 3. Flash MicroPython onto the Pico

1. Unplug the Pico. Hold the **BOOTSEL** button and plug it into USB while holding.
2. It appears as a USB drive named **RPI-RP2**.
3. Drag the MicroPython `.uf2` file onto that drive. The Pico reboots automatically,
   now running MicroPython. (The drive disappears — that's expected.)

In Thonny, choose **Run → Configure interpreter → MicroPython (Raspberry Pi Pico)** and
select the Pico's serial port. You should get a `>>>` prompt in the Shell pane.

---

## 4. Get the scripts onto the Pico ("importing to MicroPython")

MicroPython keeps a small filesystem on the Pico's flash; you copy `.py` files onto it
and `import` works exactly as on a PC. There is no compile step.

### 4a. The SD-card driver (`sdcard.py`)

The logger needs the standard MicroPython SD driver. Get it one of these ways:

- **Thonny:** Tools → Manage packages → search `sdcard` → install, **or**
- **Command line:** `mpremote mip install sdcard`

Either places `sdcard.py` on the board. (If neither works, the file is a single,
well-known module in the official MicroPython drivers directory — copy it over manually.)

### 4b. The project scripts

Copy these five files to the **root** of the Pico's filesystem:

`var.py`, `settings.py`, `logger.py`, `main.py`, `selftest.py`

- **In Thonny:** open each file, then **File → Save as… → Raspberry Pi Pico**, keeping
  the same name. (Or use the Files pane: right-click a local file → *Upload to /*.)
- **Command line:** `mpremote cp var.py settings.py logger.py main.py selftest.py :`

When done, the Pico's filesystem should contain:
`var.py  settings.py  logger.py  main.py  selftest.py  sdcard.py`

---

## 5. Prepare the SD card

Format the microSD card as **FAT32** on your computer, then insert it into the module.
The logger creates `/sd/Results/` automatically on first run; you don't need to make it.

---

## 6. Test the wiring before deploying

With the Pico connected to Thonny, at the `>>>` prompt type:

```python
import selftest
```

Expected: it lists the I²C devices (you want **`0x48`** and **`0x27`** to appear), then
reads all 12 mux channels and prints raw ADC / current / resistance for each. If the two
addresses show up and the raw values change sensibly as you change what's on the
channels, the wiring and the whole measurement path are good. (This test does not touch
the SD card.)

If an address is missing, re-check SDA/SCL, power, and grounds. See Troubleshooting below.

---

## 7. Run it

Once the self-test passes, normal operation is automatic:

- **On boot:** when the Pico powers up, `main.py` runs and launches the logger. It mounts
  the SD card, opens a new numbered pair of files in `/sd/Results/`, and begins scanning.
- **Onboard LED:** **slow blink (~0.5 Hz) = running normally.** **Fast blink = a startup
  fault** (no card, bad wiring, or SD VCC on the wrong rail) — your at-a-glance field check.
- **To run it manually / watch it live** while tethered: in the Thonny Shell, press
  `Ctrl-C` to interrupt whatever is running, then type `import logger; logger.main()` —
  or just reset the board. The live per-second table prints to the Shell over USB.
- **To stop cleanly:** press `Ctrl-C` in the Shell. It closes the files, parks the front
  end in deep sleep, and unmounts the card.

For unattended battery deployment, just power it from the pack — no computer needed. It
logs from the moment it boots.

---

## 8. Viewing data

**Live, while connected by USB:** open the Thonny Shell (or any serial terminal on the
Pico's port). Each second the logger prints an aligned table of every channel's raw value
and corrected resistance, with a header reprinted periodically. This is a display only —
it does not change what's written to the card.

**The stored CSV files** live on the card at `/sd/Results/chrono_NNNN.csv` (main) and
`chrono_NNNN_detail.csv` (detail), a fresh numbered pair per run.

The simplest way to read them is to power down, pop the microSD out, and open it on a
computer (it's plain FAT32). You can also read them over USB — see Exporting below.

---

## 9. Exporting data

**Easiest — pull the card:** power off the Pico, remove the microSD, put it in a
computer's card reader, and copy the `chrono_*.csv` files. They open directly in Excel,
LibreOffice, or `pandas.read_csv(...)`.

**Over USB (without removing the card):** because the logger owns the card while running,
first stop it with `Ctrl-C` in the Shell, then mount the card in the REPL and copy files
off. At the `>>>` prompt:

```python
import os, sdcard
from machine import Pin, SPI
import var
spi = SPI(1, baudrate=1_000_000, sck=Pin(var.SD_SCK), mosi=Pin(var.SD_MOSI), miso=Pin(var.SD_MISO))
os.mount(sdcard.SDCard(spi, Pin(var.SD_CS)), "/sd")
print(os.listdir("/sd/Results"))
```

Then, from a terminal on your computer:

```
mpremote fs cp :/sd/Results/chrono_0000.csv .
mpremote fs cp :/sd/Results/chrono_0000_detail.csv .
```

(Thonny's Files pane can also browse `/sd/Results` and download files once the card is
mounted as above.)

**Which file to use:** the **main** file (`chrono_NNNN.csv`) has the SMU-equivalent
current per device (`V_REPORT / R_device`), the number that lines up with prior 0.5 V
measurements. The **detail** file adds raw ADC counts, the actual loop current, and the
series-corrected resistance, so you can re-derive everything or debug a channel. Blank
cells mean that channel read open.

---

## 10. Clock / timestamps (important caveat)

A bare Pico has **no real-time clock**, so `time.localtime()` starts from a fixed date at
each power-up. That means:

- **`elapsed_s` is always exact** (from a monotonic counter) and is shared by all 12
  channels, so relative timing within a run and cross-channel alignment are trustworthy.
- **`iso_timestamp` is boot-relative**, not true wall-clock time, until something sets the
  clock. Runs are numbered rather than time-named so this never causes file collisions.

If you need real absolute timestamps offline, add a small **DS3231 RTC module** (battery-
backed, a few dollars) and set the clock at boot. The logger is written so this is an easy
addition — ask if you want it wired into `main.py`.

---

## 11. Tuning notes

- **Averaging window** (`AVG_WINDOW_MS`, default 75 ms in `logger.py`): each device is
  settled (`SETTLE_MS`, 3 ms) then read back-to-back for the window and all reads averaged.
  `(SETTLE + WINDOW) × 12 ≈ 0.94 s`, inside the 1 s scan. The window spans several
  50/60 Hz mains cycles to reject hum; the read count within it beats down random noise by
  ~√N. Startup prints how many reads/device actually fit on this board. Since devices are
  biased continuously, `SETTLE_MS` can likely drop toward 0.
- **TIA gain** (`TIA_SETTING` / `R_TIA`, default 2.75 kΩ, the lowest internal gain): chosen
  so VOUT clears the rail at the LMP's ~750 µA drive ceiling. If raw pins near the rail,
  lower the bias (`REFCN_BIAS_0V5`) or fit an external R_TIA below 2.75 kΩ. If raw barely
  moves off the noise floor at the cold end, raise R_TIA (accepting a lower peak). Keep
  `TIA_SETTING` and `R_TIA` consistent.
- **Series resistance** (`V_EFF`, `R_SERIES` in `var.py`): the mux + wiring add ~few-hundred
  ohms in series per channel; `device_ohms()` removes it per channel. Re-run the
  resistor-ladder calibration and update these after any rewire, reflow, or mux swap.
- **Current scaling** (`raw_to_current()`): unchanged and accurate. Zero current is at
  raw ≈ −26214 (VOUT resting at 0.5 V); raw = 0 maps to VOUT = 2.5 V, a real ~727 µA point.
  Raw ADC is logged so you can always recompute. Worth a sanity check against a known
  resistor during bring-up.

---

## 12. Power and battery life

The Pico system draws roughly **0.15–0.2 W** (≈ 35–40 mA equivalent) — the sensor chips
are negligible; the board dominates. From a typical 10,000 mAh powerbank (~30 Wh usable
after the pack's 3.7 V→5 V USB conversion) that's on the order of **a week** of continuous
logging. The loop keeps the Pico busy ~90% of each second doing ADC reads, so there's
little idle headroom; if you ever need longer runtime, shrinking `AVG_WINDOW_MS` and
sleeping between scans is the lever. Measure your actual rig with an inline USB power
meter before committing to a battery size — these are estimates.

---

## 13. Troubleshooting

- **LED blinks fast, nothing logs.** A startup fault. Most often the SD card: check it's
  inserted, formatted FAT32, that its **VCC is on 5 V (not 3.3 V)**, that the SPI lines go
  to GP10–13, and that `sdcard.py` is on the board. The Shell prints the specific reason
  if you connect over USB.
- **Self-test doesn't show `0x48` or `0x27`.** I²C wiring/power issue: check SDA→GP8,
  SCL→GP9, that both chips have 3.3 V and share ground, and that the LMP is getting its
  5 V analog supply.
- **Raw values look stuck or railed.** See the TIA gain / bias notes in §11.
- **Files start over at `chrono_0000` unexpectedly.** Expected if the card was reformatted
  or swapped; numbering is derived from the files present in `/sd/Results/`.
- **Timestamps all show the same date.** Expected without an RTC — see §10; use `elapsed_s`.

---

*Derivative of CVGIT (Aznar-Poveda et al., Technical University of Cartagena) and the
AIRBORNE Raspberry Pi Zero W logger. Released under AGPL-3.0 — see `LICENSE` and the
README for full attribution.*

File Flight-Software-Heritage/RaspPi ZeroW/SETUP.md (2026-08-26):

# Headless 12-device chronoamperometry logger (Raspberry Pi Zero W, Pi OS Trixie)

Holds 12 CNT-on-interdigitated-electrode devices at a constant +0.5 V and logs
their current once per second to a CSV file. No screen, no GUI: it starts on
boot, blinks the onboard LED to show it is running, and writes crash-safely.

## Files

- `var.py`      - I2C/SPI setup + all register/hardware constants (bias, gain, addresses)
- `settings.py` - low-level helpers (LMP register writes, ADC read, mux select, conversion)
- `logger.py`   - the main loop (run this)
- `chrono-logger.service` - systemd unit for auto-start on boot

Put all files in one folder. The service expects `/home/airborne/Documents/AIRBORNE`;
edit the unit's two paths if you use a different location. See Install below.

## Hardware map (as wired)

- LMP91000EVM: I2C @ 0x48, SPI on SPI0/CE0. 2-WIRE jumper set = CE-RE shorted (2-electrode
               wiring). LMP register op-mode stays 3-lead amperometric: the potentiostat amp
               A1 still drives the shorted CE/RE node to hold the bias. 
- MCP23017:    I2C @ 0x27 (A2/A1/A0 all high). VCC = 3.3 V. Port A bits 0-3 -> mux S0-S3.
- CD74HC4067:  VCC = 3.3 V, EN tied to GND (always enabled). Common line -> LMP WE/TIA input.
               Channels 0-11 -> the 12 devices. All devices share the always-on 0.5 V bias.
- Bias/gain:   +0.5 V (REFCN 10011011, internal zero 20%), R_TIA = 2.75 kOhm. Both tunable in var.py.

## Connection map
Only connections that should need to made are to the Pi.  As shipped on 7/6/25 labels include final location

Color guide:

  Red      --> Pin 1  (3.3 V)
  
  Orange   --> Pin 2  (5 V)
  
  Green    --> Pin 3  (SDA)
  
  L.Blue   --> Pin 5  (SCL)
  
  Black    --> Pin 6  (GND)
  
  L.Green  --> Pin 19 (MOSI)
  
  D.Blue   --> Pin 21 (MISO)
  
  Purple   --> Pin 23 (SCLK)
  
  White    --> Pin 24 (CE0)

  Red/Black banana plugs go to WE and RE (tied to CE), respectively on LMP

## Install (get the code)

Clone the repository to the path the service file expects,
`/home/airborne/Documents/AIRBORNE` (clone as the `airborne` user so `~` resolves
there; if you put it elsewhere, update the two paths in `chrono-logger.service`):

    sudo apt install git
    mkdir -p ~/Documents
    cd ~/Documents
    git clone https://github.com/zac84-pittedu/AIRBORNE.git
    cd AIRBORNE

You now have `logger.py`, `settings.py`, `var.py`, `chrono-logger.service`, and
the docs; `Results/` is created automatically on the first run. To update later:

    cd ~/Documents/AIRBORNE && git pull

## One-time Pi setup

    sudo apt update
    sudo apt install python3-smbus python3-spidev i2c-tools

    sudo raspi-config     # Interface Options -> enable I2C AND SPI, then reboot
    sudo reboot

Confirm both chips are on the bus (with the LMP connected):

    sudo i2cdetect -y 1   # expect 0x27 (MCP) and 0x48 (LMP)

Note: numpy / matplotlib / tkinter are NOT needed by this headless version.

## Test run (before enabling the service)

    cd ~/Documents/AIRBORNE
    sudo python3 logger.py

It prints the output filename and starts scanning; the onboard LED blinks ~1 Hz.
Ctrl-C stops it cleanly (file closed, front end parked, LED restored). Check the
newest file in `Results/` and confirm two files (main + _detail) with one row per second.

## Auto-start on boot

    sudo cp chrono-logger.service /etc/systemd/system/
    sudo systemctl daemon-reload
    sudo systemctl enable chrono-logger.service    # start at every boot
    sudo systemctl start  chrono-logger.service    # start now

    systemctl status chrono-logger.service         # check state
    journalctl -u chrono-logger.service -f         # watch its output live

To stop: `sudo systemctl stop chrono-logger.service` (this closes the file
cleanly). To disable auto-start: `sudo systemctl disable chrono-logger.service`.

## Output format

Two comma-separated files per run, one row per scan:

  MAIN   Results/chrono_YYYY-MM-DD_HHMMSS.csv  (simple):
    iso_timestamp, elapsed_s, dev00_current_uA, ... dev11_current_uA
    -> devNN_current_uA = SMU-equivalent current V_REPORT/R_device (V_REPORT=0.5 V),
       computed from the corrected resistance; relates to prior 0.5 V data. Blank if open.

  DETAIL Results/chrono_YYYY-MM-DD_HHMMSS_detail.csv:
    iso_timestamp, elapsed_s, dev00_raw, dev00_actual_uA, dev00_R_ohm, ... dev11_R_ohm
    -> raw ADC, actual (mux-taxed) loop current, and series-corrected R_ohm (blank if open).

Each device value per row is the MEAN of all ADC reads taken during a ~75 ms
window for that device (mean raw ADC and the current computed from it). The
number of reads averaged depends on the board's per-read speed (tens to a couple
hundred on a Zero W) and is printed once at startup. Individual reads are not
stored. Note when reporting: one point/device/second = mean of ~N reads.

- `elapsed_s` comes from a monotonic clock and is always reliable.
- `iso_timestamp` is wall-clock time (see clock caveat below).
- Each row is flushed and fsync'd to the SD card immediately, so an unexpected
  power loss costs at most the row in progress, never the whole run.

## Things to know / tune

- CURRENT SCALING: the raw->current formula is carried over from the original
  project and is accurate. With the internal zero now at 20% of VREF, zero current
  corresponds to raw ~= -26214 (VOUT resting at INT_ZERO_V = 0.5 V), where the
  formula returns ~0 uA; at 2.75 kOhm the scale is ~36 counts/uA. raw = 0 maps to
  VOUT = VREF = 2.5 V, a real ~727 uA point, not the baseline -- so there is no
  offset in the data and absolute current is trustworthy, not just relative change.
  Raw ADC is logged alongside current, so you can still recompute later. During
  bring-up it is worth checking the scaling against a known resistor.

- SERIES RESISTANCE: the mux + wiring add ~318 ohm in series with each device.
  settings.device_ohms() removes it per channel (R_device = V_EFF/I_loop -
  R_SERIES[ch]) and logs the result as devNN_R_ohm. V_EFF (~0.51 V) and the
  12-entry R_SERIES table are in var.py, from the resistor-ladder calibration;
  re-run and update them after any rewire, reflow, or mux swap. At the 200 ohm
  warm end this subtracts ~318 of ~518 ohm, so accuracy rides on R_SERIES
  stability -- a low-R_on mux (e.g. ADG706) would make the correction negligible.

- TIA GAIN: fixed at 2.75 kOhm, the LOWEST internal gain, chosen so VOUT clears
  the rail at the LMP's ~750 uA drive ceiling. Being the floor, you cannot drop
  gain further internally: if raw still pins near the rail, lower the bias
  (REFCN_BIAS_0V5) or fit an external R_TIA below 2.75 kOhm. If raw barely moves
  off the noise floor at the cold end, raise R_TIA (accepting a lower peak) or
  switch gains per scan. Keep TIA_SETTING and R_TIA consistent.

- TIMING: in logger.py. Each device is settled (SETTLE_S = 3 ms) then read
  back-to-back for AVG_WINDOW_S = 75 ms and all reads averaged. (SETTLE + WINDOW)
  x 12 ~= 0.94 s, leaving margin in the 1 s interval. The window length rejects
  50/60 Hz mains pickup; the read COUNT within it cuts random noise by ~sqrt(N).
  Raise AVG_WINDOW_S toward 0.08 to use more of the second; lower it for a faster
  cadence. Startup prints how many reads/device actually fit on your board -- if
  you want to check that number directly, time readadc() in a loop first.
  Devices are biased continuously, so SETTLE_S can likely drop toward 0.

- CLOCK: the Zero W has no real-time clock. Deployed without network, the
  wall-clock timestamp will be whatever fake-hwclock restored at boot until (if
  ever) NTP corrects it. This does NOT affect syncing with other sensors on the
  SAME Pi - they all share the same system clock, so relative alignment holds,
  and elapsed_s is exact regardless. Only ABSOLUTE wall time is uncertain. If
  you need trustworthy absolute timestamps offline, add a small RTC module.

- RESILIENCE: a hard crash triggers a systemd restart into a NEW file (small
  gap, no data lost). If you see transient I2C read glitches in the field, we
  can add per-read error handling so one bad read never interrupts a run - easy
  add, left out for now to keep the loop simple.

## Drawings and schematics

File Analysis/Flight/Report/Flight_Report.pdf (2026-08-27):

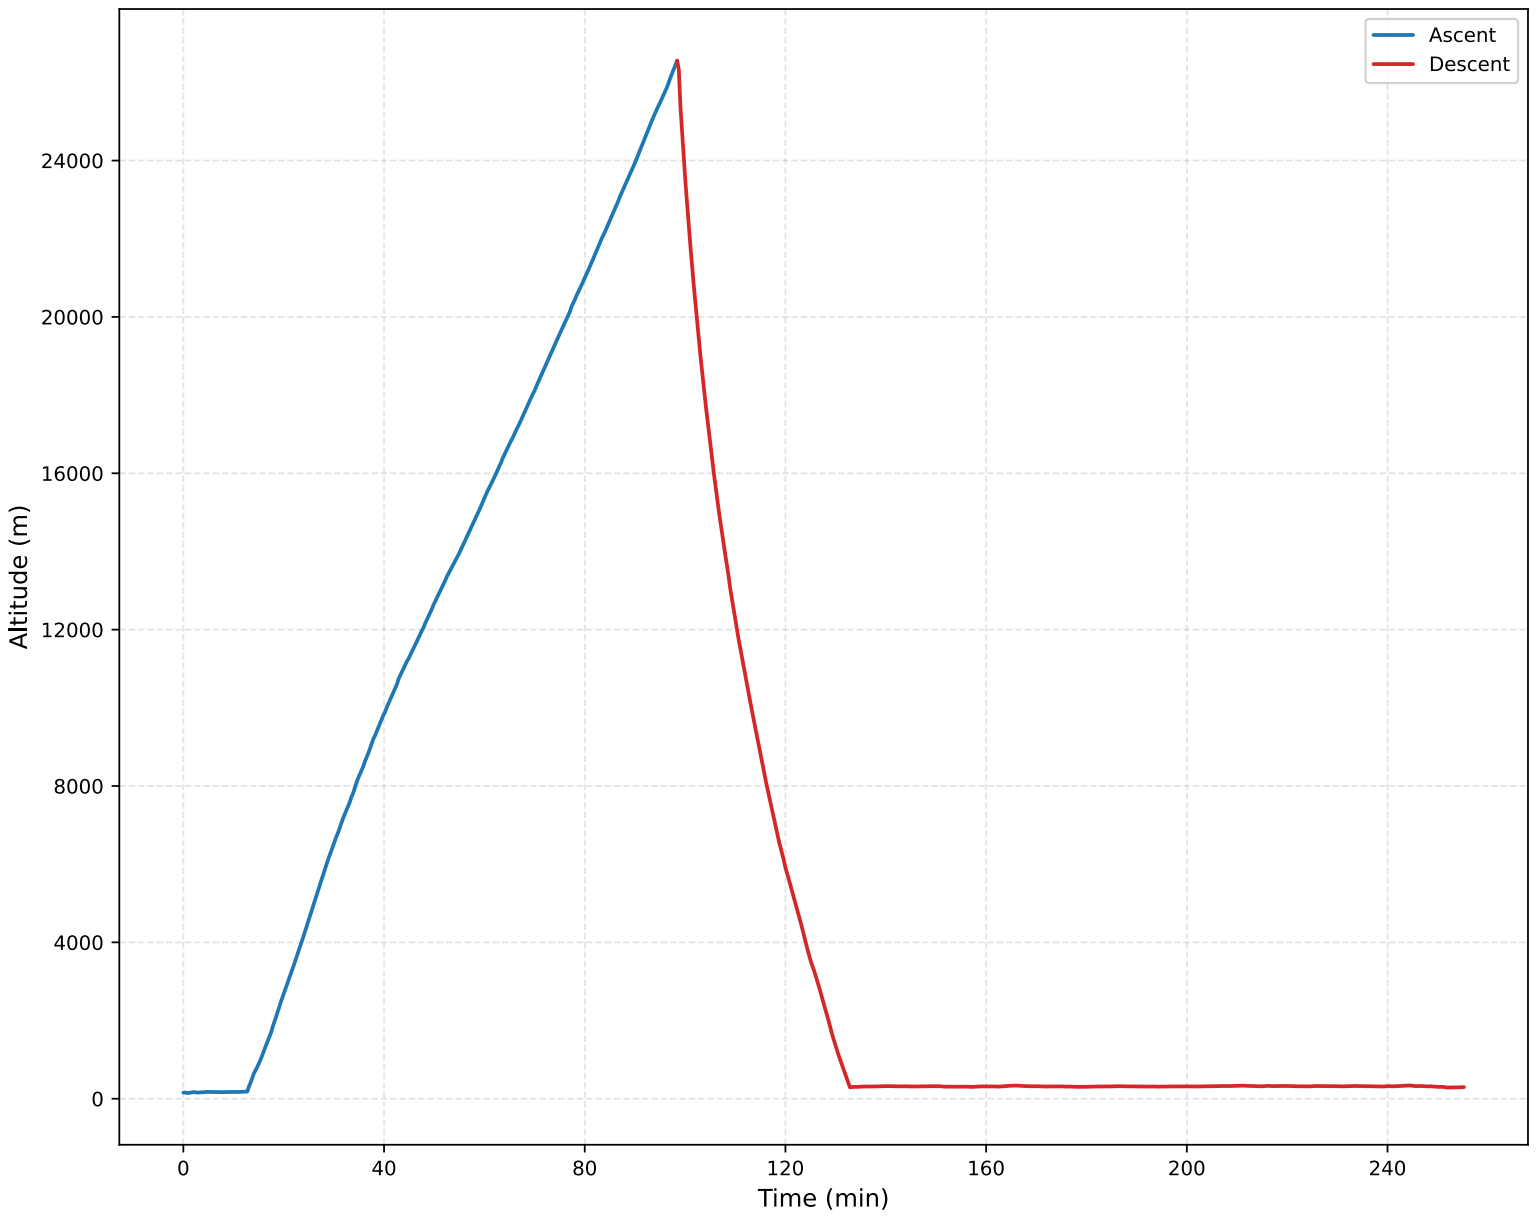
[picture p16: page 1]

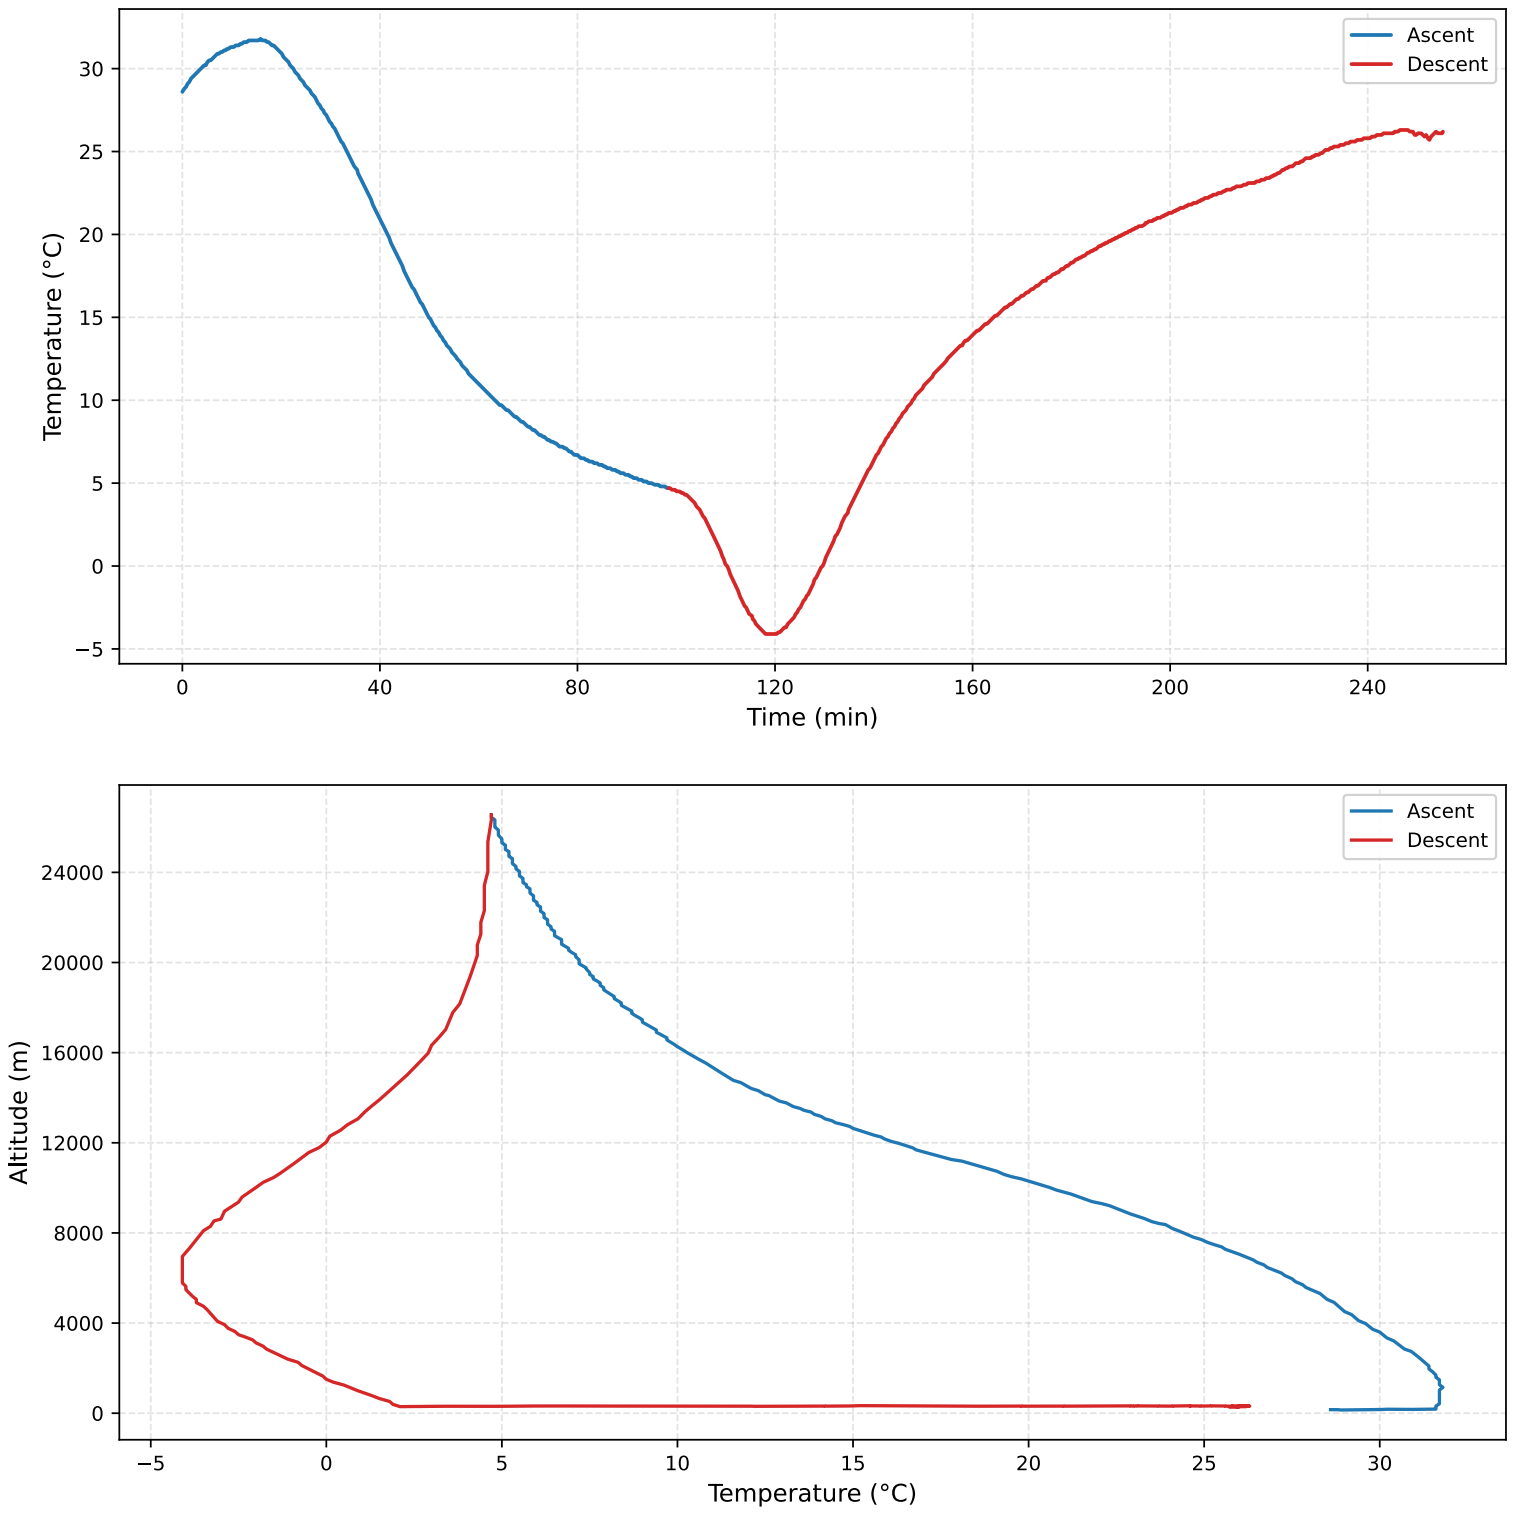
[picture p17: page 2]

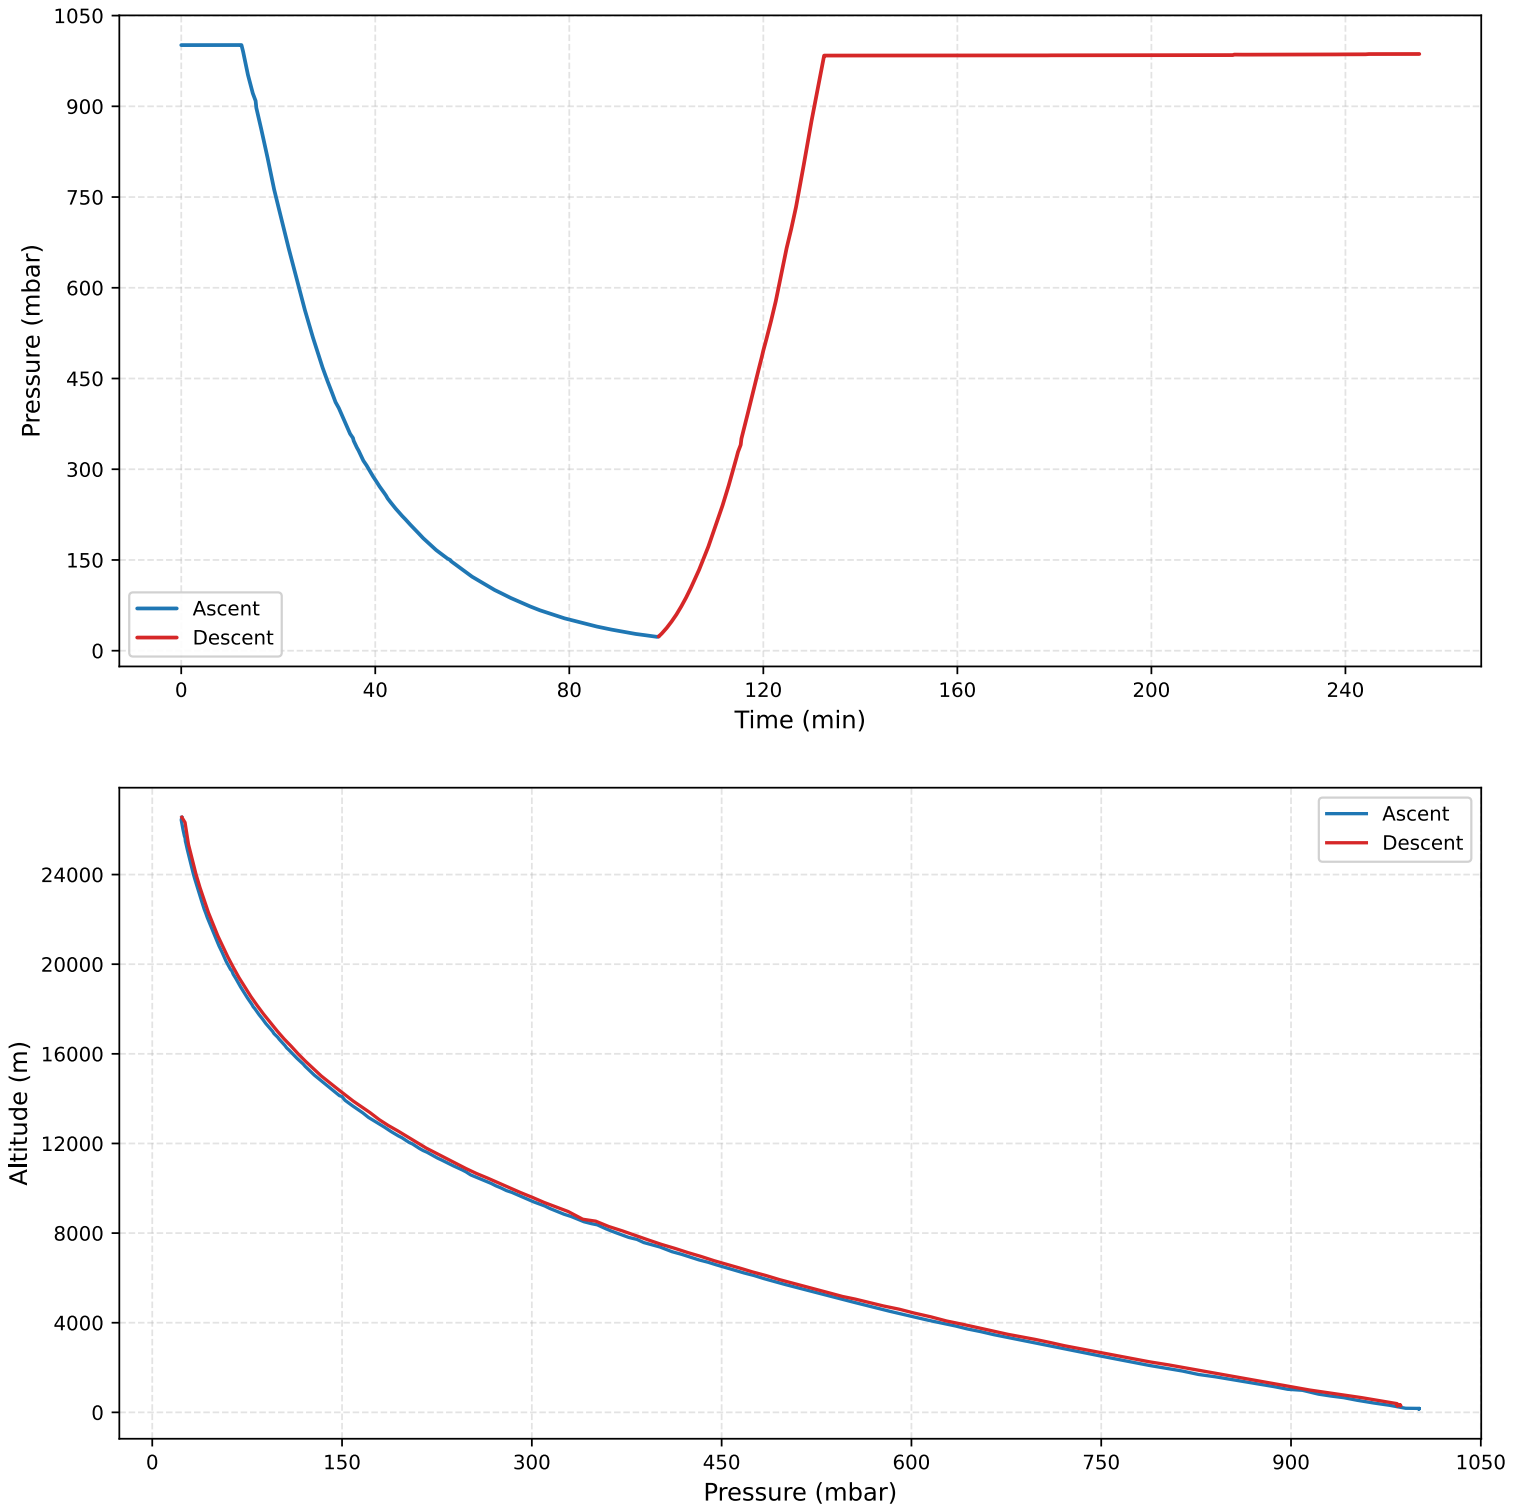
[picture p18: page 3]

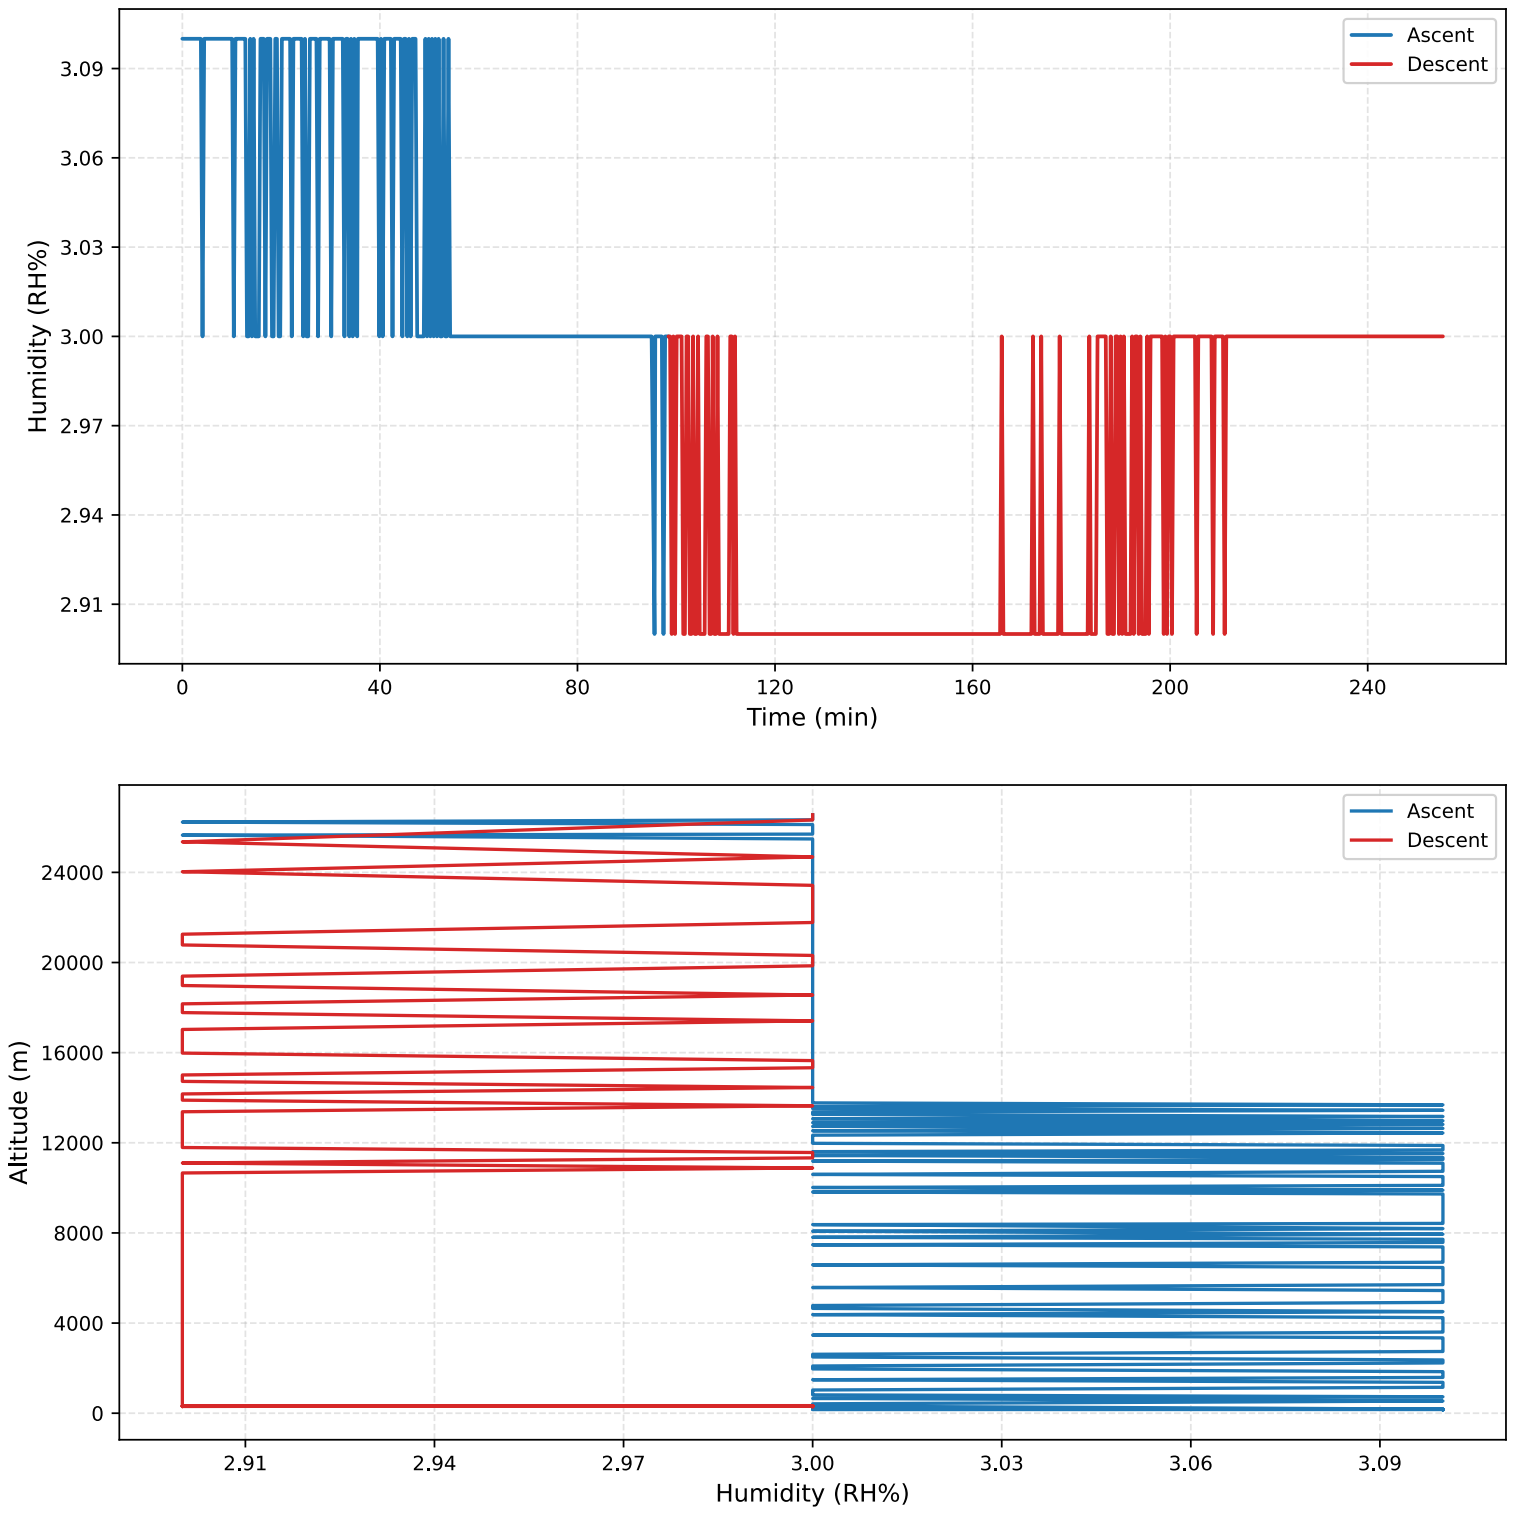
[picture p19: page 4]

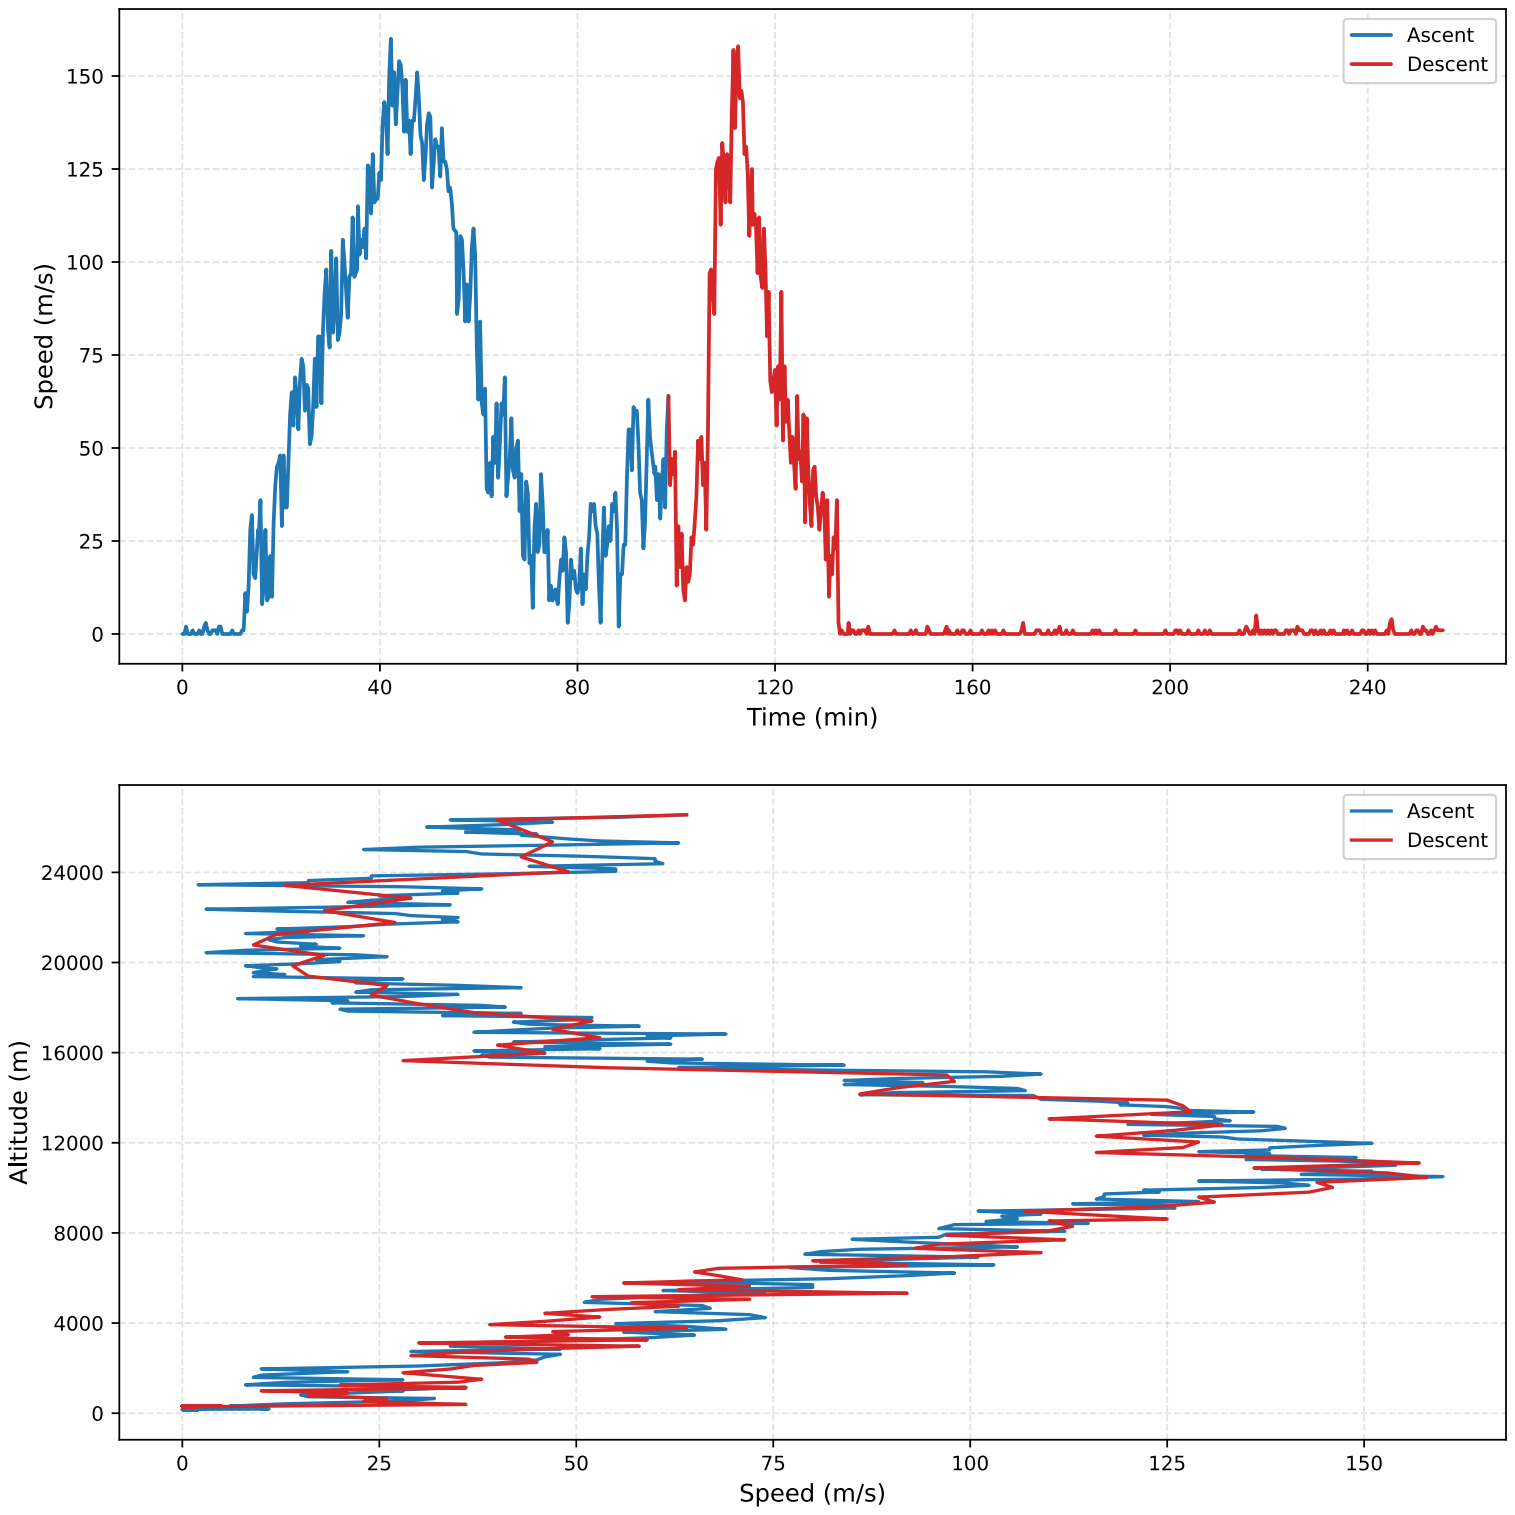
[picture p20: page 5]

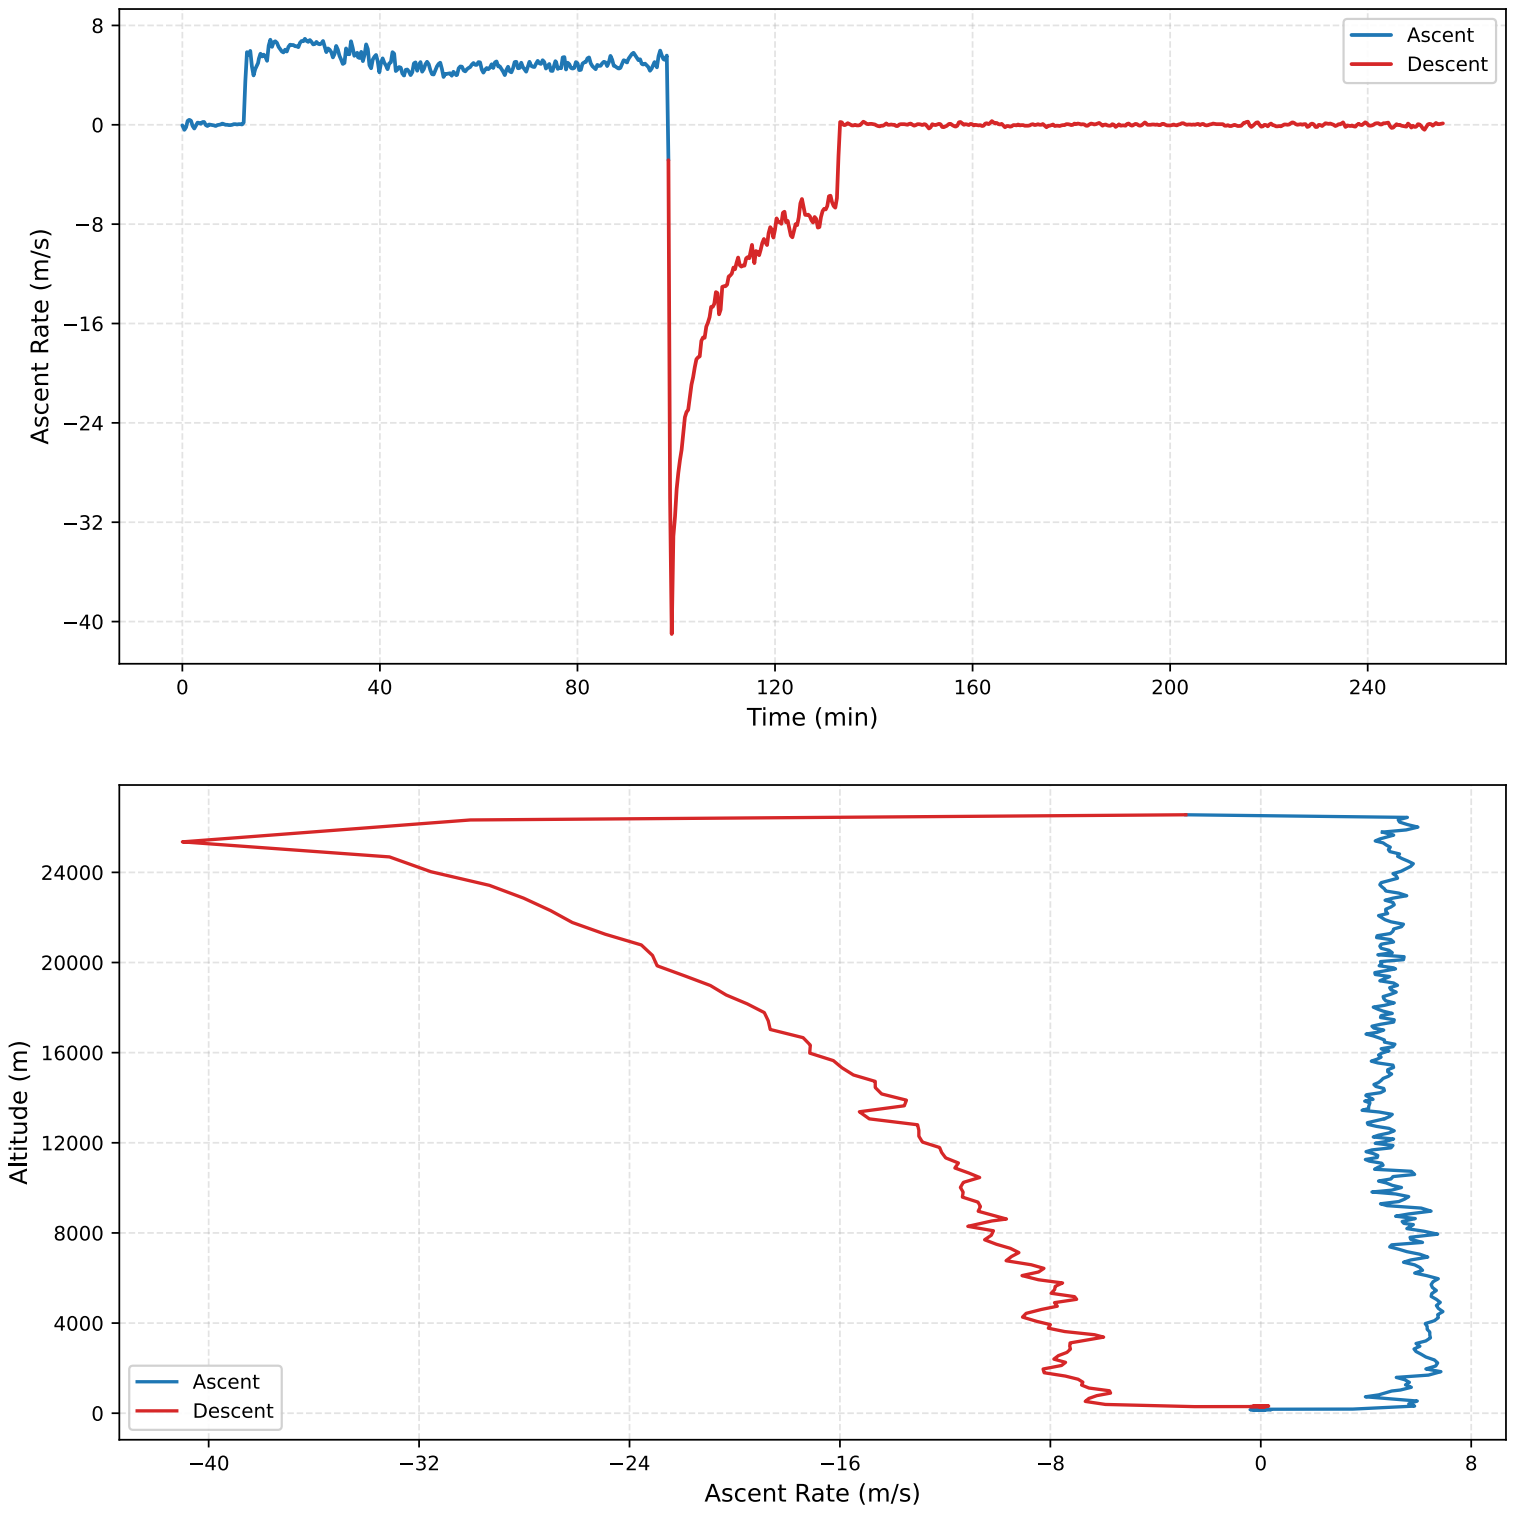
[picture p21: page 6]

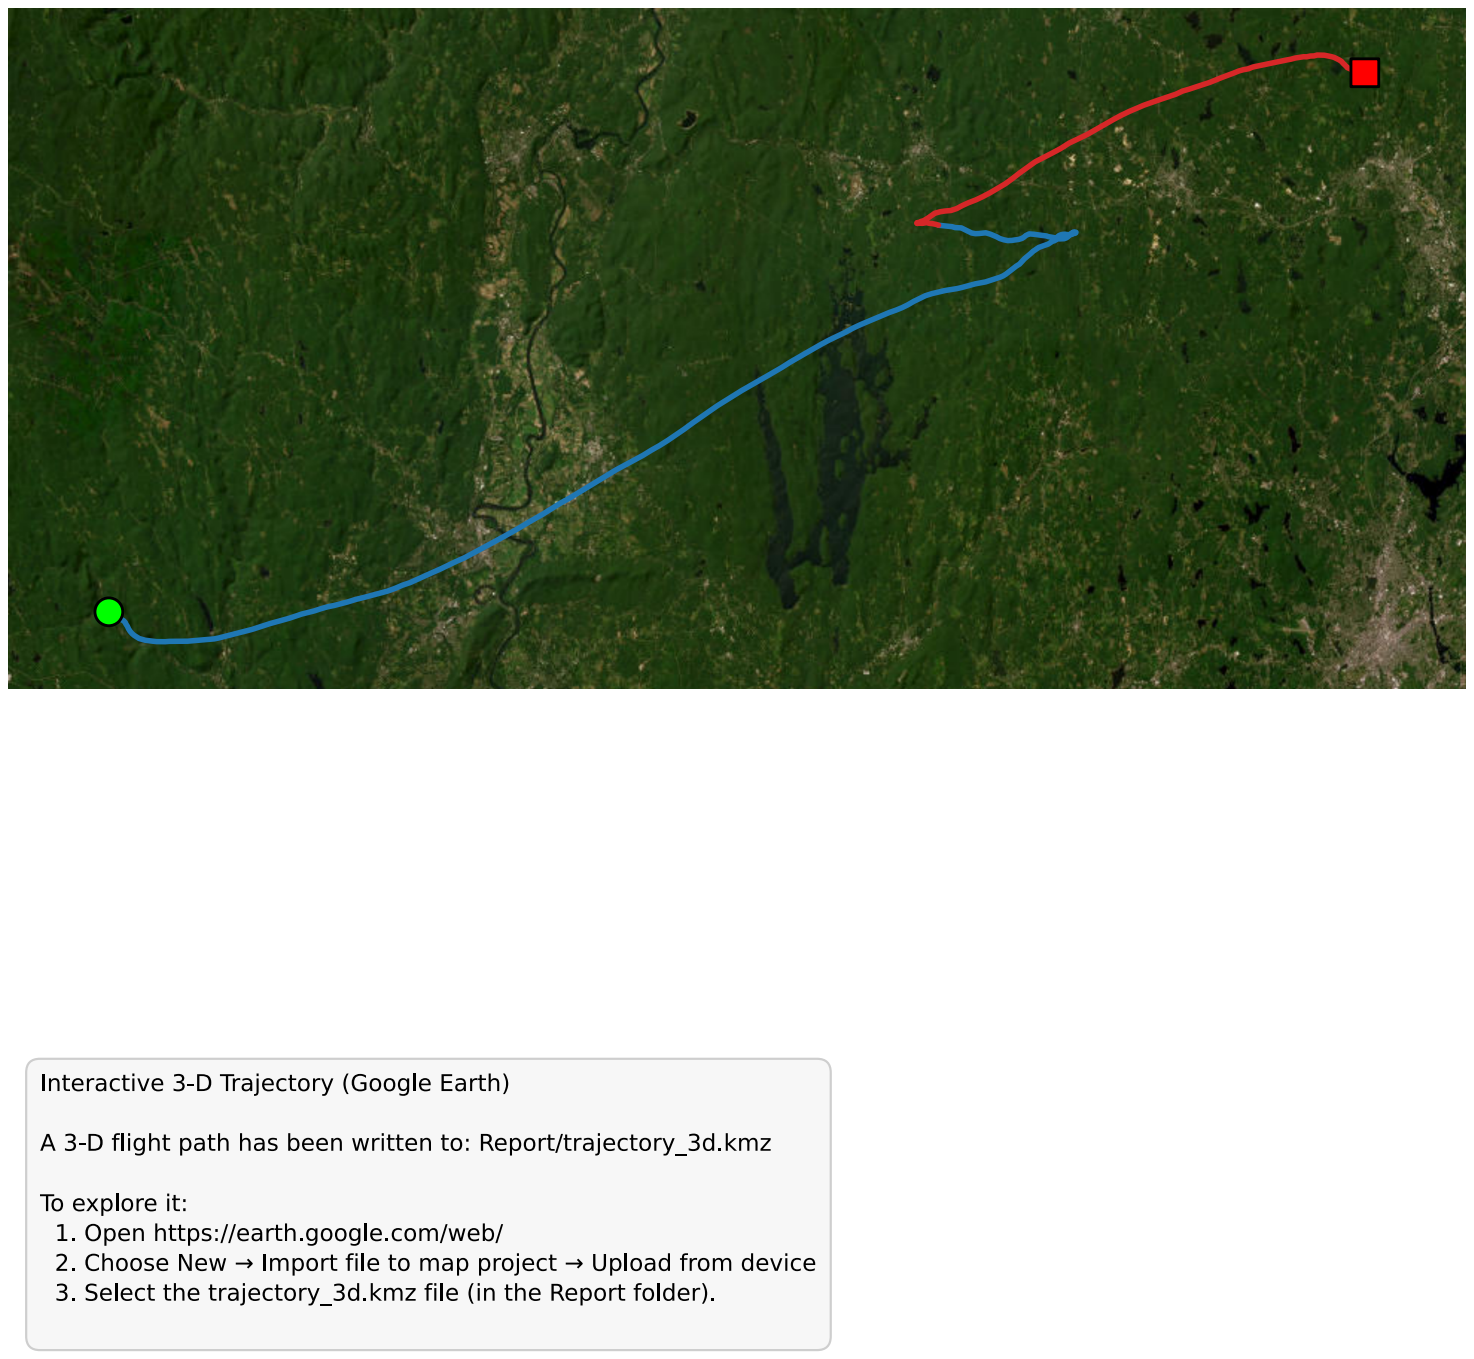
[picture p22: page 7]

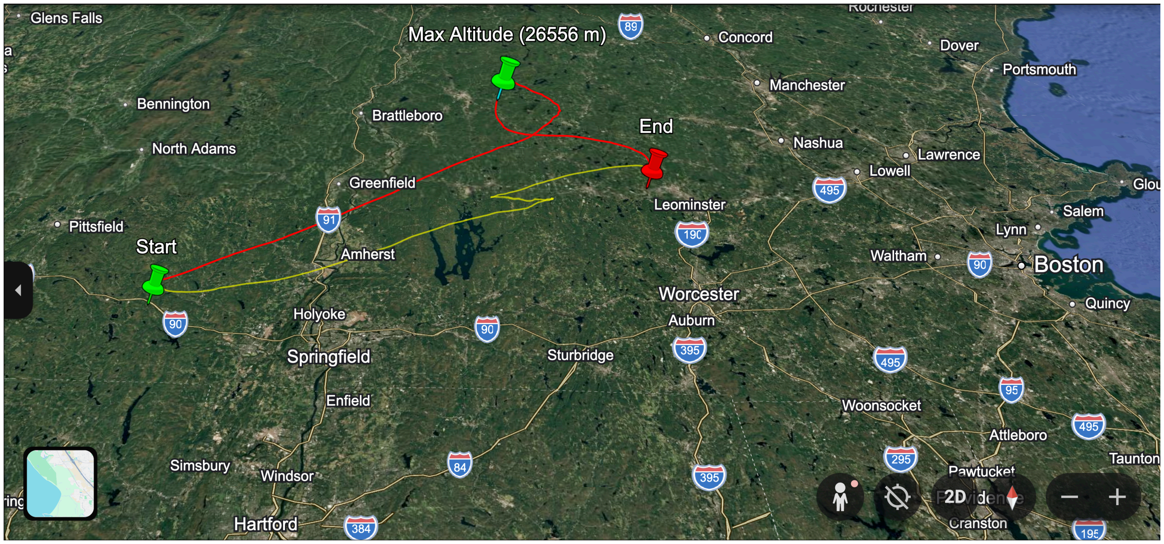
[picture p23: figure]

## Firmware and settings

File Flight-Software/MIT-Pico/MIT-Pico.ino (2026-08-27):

#include "pinout.h"
#include "sd_log.h"
#include "sensors.h"
#include "heaters.h"
#include "downlink.h"

void setup()
{
    pinMode(LED_STATUS, OUTPUT);
    digitalWrite(LED_STATUS, LOW);
    pinMode(LED_ONBOARD, OUTPUT);
    digitalWrite(LED_ONBOARD, LOW);

    pinMode(MOSFET_PIN, OUTPUT);
    digitalWrite(MOSFET_PIN, HIGH);

    Serial.begin(USB_SERIAL_BAUD);
    delay(1000);
    Serial.println(F("Full production-style logger starting..."));

    if (!initSensors())
    {
        errorBlink();
    }

    initDownlink();
    performStartupSequence();

    lastFlushMs = millis();
    lastBnoUs = micros();
    lastSuiteUs = micros();
}

// Double-buffer invariant (do not break without a bounds check in writeRecord):
//   requestFlush() swaps to an empty buffer and sets flushPending.
//   serviceFlush() must run on the same core, in this loop(), before that
//   new buffer can fill. owc is blocking, so writeRecord is not called
//   during the SD transfer. flushPending is cleared when owc returns.
// Original code is safe because sampling cannot outrun a pending flush.
// Unsafe if flush becomes asynchronous, if records are written from an
// ISR / onRequest, or if serviceFlush() is removed from the bottom of
// loop(). In any of those cases writeRecord() must refuse the memcpy
// when requestFlush() cannot swap, or it will write off the end of the
// active 24 KB buffer.
void loop()
{
    unsigned long nowMs = millis();
    unsigned long nowUs = micros();

    pollBno(nowUs);
    pollSuite(nowUs);
    pollXy(nowUs);

    if (nowMs - lastFlushMs >= FLUSH_INTERVAL_MS)
    {
        requestFlush();
    }
    serviceFlush();
}

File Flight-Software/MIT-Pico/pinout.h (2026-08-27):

#pragma once

#include <Arduino.h>

// Pins (pico_wiring.txt)
static const uint8_t XY1_TX_PIN = 0;       // GP0 UART0 TX
static const uint8_t XY1_RX_PIN = 1;       // GP1 UART0 RX
static const uint8_t I2C1_SDA_PIN = 2;     // GP2 Tiny4FSK SDA
static const uint8_t I2C1_SCL_PIN = 3;     // GP3 Tiny4FSK SCL
static const uint8_t I2C0_SDA_PIN = 4;     // GP4 sensor SDA
static const uint8_t I2C0_SCL_PIN = 5;     // GP5 sensor SCL
static const uint8_t BNO_INT_PIN = 6;      // GP6 wired, unused in software
static const uint8_t BNO_RST = 7;          // GP7
static const uint8_t XY2_TX_PIN = 8;       // GP8 UART1 TX
static const uint8_t XY2_RX_PIN = 9;       // GP9 UART1 RX
static const uint8_t MOSFET_PIN = 10;      // GP10 digital enable
static const uint8_t LED_STATUS = 15;      // GP15
static const uint8_t SPI0_RX_PIN = 16;     // GP16 MISO
static const uint8_t SD_CS = 17;           // GP17
static const uint8_t SPI0_SCK_PIN = 18;    // GP18
static const uint8_t SPI0_TX_PIN = 19;     // GP19 MOSI
static const uint8_t MAX_CS = 20;          // GP20
static const uint8_t LED_ONBOARD = LED_BUILTIN; // GP25

// I2C
static const uint8_t TINY4FSK_SLAVE_ADDR = 0x09;
static const uint32_t I2C1_FREQ = 400000;
static const uint32_t I2C0_FREQ = 100000;
static const uint8_t BNO086_ADDR = 0x4B;
static const uint8_t MS5611_ADDR = 0x77;

// UART
static const uint32_t XY_BAUD = 9600;
static const uint32_t USB_SERIAL_BAUD = 115200;

// MAX31865
static const float MAX_RREF = 430.0f;
static const float MAX_RNOMINAL = 100.0f;
static const uint32_t MAX_SPI_HZ = 500000;

// Timing
static const unsigned long ALIVE_BLINK_MS = 10000;
static const unsigned long BNO_INTERVAL_US = 10000;
static const unsigned long SUITE_INTERVAL_US = 50000;
static const unsigned long FLUSH_INTERVAL_MS = 2000;

// Buffer sizes
static const size_t BUFFER_SIZE = 24 * 1024;
static const size_t FLUSH_THRESHOLD = (BUFFER_SIZE * 80) / 100;
static const size_t XY_LINE_BUF_SIZE = 40;
static const size_t LOG_FILENAME_SIZE = 32;

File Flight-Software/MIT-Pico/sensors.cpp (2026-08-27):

#include <Arduino.h>
#include "sensors.h"

#include <Wire.h>
#include <SPI.h>
#include <Adafruit_BNO08x.h>
#include <Adafruit_MAX31865.h>
#include <Adafruit_SHT4x.h>
#include <MS5611.h>
#include "pinout.h"
#include "records.h"
#include "sd_log.h"
#include "heaters.h"
#include "downlink.h"

unsigned long lastBnoUs = 0;
unsigned long lastSuiteUs = 0;

static Adafruit_BNO08x bno08x(BNO_RST);
static Adafruit_MAX31865 max31865(MAX_CS);
static MS5611 ms5611(MS5611_ADDR);
static Adafruit_SHT4x sht4;

static float bno_ax = 0, bno_ay = 0, bno_az = 0;
static float bno_gx = 0, bno_gy = 0, bno_gz = 0;
static float bno_mx = 0, bno_my = 0, bno_mz = 0;
static float bno_qw = 0, bno_qx = 0, bno_qy = 0, bno_qz = 0;
static bool bnoHasData = false;

void prepareMax31865Bus()
{
    digitalWrite(SD_CS, HIGH);
    SPI.beginTransaction(SPISettings(MAX_SPI_HZ, MSBFIRST, SPI_MODE1));
}

void recoverMax31865Bus()
{
    digitalWrite(SD_CS, HIGH);
    digitalWrite(MAX_CS, HIGH);
    delayMicroseconds(50);

    SPI.beginTransaction(SPISettings(MAX_SPI_HZ, MSBFIRST, SPI_MODE1));

    max31865.enableBias(true);
    delay(5);
    max31865.clearFault();
    delay(5);
}

bool readMax31865Safe(uint16_t &raw, float &ratio, float &resistance,
                      float &temperature, uint8_t &fault)
{
    const int MAX_ATTEMPTS = 3;

    for (int attempt = 0; attempt < MAX_ATTEMPTS; attempt++)
    {
        prepareMax31865Bus();

        raw = max31865.readRTD();
        ratio = raw / 32768.0f;
        resistance = MAX_RREF * ratio;
        temperature = max31865.calculateTemperature(raw, MAX_RNOMINAL, MAX_RREF);
        fault = max31865.readFault();
        if (fault)
            max31865.clearFault();

        bool garbage = (raw == 0) || (temperature < -200.0f);

        if (!garbage)
        {
            return true;
        }

        recoverMax31865Bus();
        delay(10);
    }

    return false;
}

bool initSensors()
{
    pinMode(MAX_CS, OUTPUT);
    digitalWrite(MAX_CS, HIGH);

    if (!initLog())
        return false;

    delay(100);

    SPI.beginTransaction(SPISettings(MAX_SPI_HZ, MSBFIRST, SPI_MODE1));

    prepareMax31865Bus();
    if (!max31865.begin(MAX31865_3WIRE))
    {
        Serial.println(F("MAX31865 init failed"));
        return false;
    }
    max31865.enableBias(true);
    max31865.clearFault();

    Wire.setSDA(I2C0_SDA_PIN);
    Wire.setSCL(I2C0_SCL_PIN);
    Wire.begin();
    Wire.setClock(I2C0_FREQ);

    if (!bno08x.begin_I2C(BNO086_ADDR, &Wire))
    {
        Serial.println(F("BNO086 init failed"));
        return false;
    }
    bno08x.enableReport(SH2_ACCELEROMETER, BNO_INTERVAL_US);
    bno08x.enableReport(SH2_GYROSCOPE_CALIBRATED, BNO_INTERVAL_US);
    bno08x.enableReport(SH2_MAGNETIC_FIELD_CALIBRATED, BNO_INTERVAL_US);
    bno08x.enableReport(SH2_ROTATION_VECTOR, BNO_INTERVAL_US);

    if (!ms5611.begin())
    {
        Serial.println(F("MS5611 init failed"));
        return false;
    }

    if (!sht4.begin(&Wire))
    {
        Serial.println(F("SHT45 init failed"));
        return false;
    }

    initXy();

    return true;
}

void pollBno(unsigned long nowUs)
{
    if (nowUs - lastBnoUs < BNO_INTERVAL_US)
        return;

    lastBnoUs = nowUs;

    sh2_SensorValue_t event;
    while (bno08x.getSensorEvent(&event))
    {
        switch (event.sensorId)
        {
        case SH2_ACCELEROMETER:
            bno_ax = event.un.accelerometer.x;
            bno_ay = event.un.accelerometer.y;
            bno_az = event.un.accelerometer.z;
            break;
        case SH2_GYROSCOPE_CALIBRATED:
            bno_gx = event.un.gyroscope.x;
            bno_gy = event.un.gyroscope.y;
            bno_gz = event.un.gyroscope.z;
            break;
        case SH2_MAGNETIC_FIELD_CALIBRATED:
            bno_mx = event.un.magneticField.x;
            bno_my = event.un.magneticField.y;
            bno_mz = event.un.magneticField.z;
            break;
        case SH2_ROTATION_VECTOR:
            bno_qw = event.un.rotationVector.real;
            bno_qx = event.un.rotationVector.i;
            bno_qy = event.un.rotationVector.j;
            bno_qz = event.un.rotationVector.k;
            bnoHasData = true;
            break;
        }
    }

    if (bnoHasData)
    {
        BnoRecord rec;
        rec.type = REC_BNO086;
        rec.timestamp_us = nowUs;
        rec.sequence = globalSequence++;
        rec.ax = bno_ax;
        rec.ay = bno_ay;
        rec.az = bno_az;
        rec.gx = bno_gx;
        rec.gy = bno_gy;
        rec.gz = bno_gz;
        rec.mx = bno_mx;
        rec.my = bno_my;
        rec.mz = bno_mz;
        rec.qw = bno_qw;
        rec.qx = bno_qx;
        rec.qy = bno_qy;
        rec.qz = bno_qz;
        writeRecord(&rec, sizeof(rec));
    }
}

void pollSuite(unsigned long nowUs)
{
    if (nowUs - lastSuiteUs < SUITE_INTERVAL_US)
        return;

    lastSuiteUs = nowUs;

    SuiteRecord rec;
    rec.type = REC_SUITE;
    rec.timestamp_us = nowUs;
    rec.sequence = globalSequence++;

    uint16_t raw;
    float ratio, resistance, temperature;
    uint8_t fault;
    bool maxOk = readMax31865Safe(raw, ratio, resistance, temperature, fault);

    if (maxOk)
    {
        rec.max_raw = raw;
        rec.max_ratio = ratio;
        rec.max_resistance = resistance;
        rec.max_temp = temperature;
        rec.max_fault = fault;
    }
    else
    {
        rec.max_raw = 0;
        rec.max_ratio = 0;
        rec.max_resistance = 0;
        rec.max_temp = -999.0f;
        rec.max_fault = 0xFF;
    }

    bool msOk = (ms5611.read() == MS5611_READ_OK);
    if (msOk)
    {
        rec.ms_temp = ms5611.getTemperature();
        rec.ms_pressure = ms5611.getPressure();
    }
    else
    {
        rec.ms_temp = NAN;
        rec.ms_pressure = NAN;
    }

    sensors_event_t hum, tem;
    bool shtOk = sht4.getEvent(&hum, &tem);
    rec.sht_temp = shtOk ? tem.temperature : NAN;
    rec.sht_humidity = shtOk ? hum.relative_humidity : NAN;
    rec.sht_crc_ok = shtOk ? 1 : 0;

    writeRecord(&rec, sizeof(rec));
    downlinkUpdateSuite(maxOk, rec.max_temp, msOk, rec.ms_temp, rec.ms_pressure,
                        shtOk, rec.sht_temp, rec.sht_humidity);
}

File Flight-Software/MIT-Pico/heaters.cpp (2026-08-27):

#include <Arduino.h>
#include "heaters.h"

#include "pinout.h"
#include "records.h"
#include "sd_log.h"
#include "downlink.h"

static uint8_t xy1Len = 0;
static uint8_t xy2Len = 0;
static char xy1Buf[XY_LINE_BUF_SIZE];
static char xy2Buf[XY_LINE_BUF_SIZE];

void errorBlink()
{
    while (true)
    {
        digitalWrite(LED_ONBOARD, HIGH);
        digitalWrite(LED_STATUS, HIGH);
        delay(50);
        digitalWrite(LED_ONBOARD, LOW);
        digitalWrite(LED_STATUS, LOW);
        delay(50);
    }
}

void sendCommand(HardwareSerial &port, const char *cmd)
{
    port.print(cmd);
    port.flush();
}

float extractTemperature(const String &line)
{
    int i = 0;
    while (i < (int)line.length() &&
           !(isDigit(line[i]) || line[i] == '-' || line[i] == '.'))
        i++;
    if (i >= (int)line.length())
        return NAN;
    String num;
    while (i < (int)line.length() &&
           (isDigit(line[i]) || line[i] == '.' || line[i] == '-'))
    {
        num += line[i++];
    }
    if (num.length() == 0)
        return NAN;
    return num.toFloat();
}

void initXy()
{
    Serial1.setTX(XY1_TX_PIN);
    Serial1.setRX(XY1_RX_PIN);
    Serial1.begin(XY_BAUD);
    Serial2.setTX(XY2_TX_PIN);
    Serial2.setRX(XY2_RX_PIN);
    Serial2.begin(XY_BAUD);
    delay(100);

    sendCommand(Serial1, "ON");
    sendCommand(Serial2, "ON");
    delay(50);
    sendCommand(Serial1, "start");
    sendCommand(Serial2, "start");
}

void performStartupSequence()
{
    unsigned long aliveBlinkStartMs = millis();
    unsigned long phaseStart = millis();

    sendCommand(Serial1, "S:100");
    sendCommand(Serial2, "S:100");

    bool zeroSent = false;
    bool twentySent = false;

    while (millis() - aliveBlinkStartMs < ALIVE_BLINK_MS)
    {
        bool on = ((millis() - aliveBlinkStartMs) / 500) % 2 == 0;
        digitalWrite(LED_STATUS, on ? HIGH : LOW);

        unsigned long elapsed = millis() - phaseStart;

        if (elapsed >= 1000 && !zeroSent)
        {
            sendCommand(Serial1, "S:000");
            sendCommand(Serial2, "S:000");
            zeroSent = true;
        }
        if (elapsed >= 2000 && !twentySent)
        {
            sendCommand(Serial1, "S:020");
            sendCommand(Serial2, "S:020");
            twentySent = true;
        }
    }

    digitalWrite(LED_STATUS, LOW);
}

void pollXy(unsigned long nowUs)
{
    while (Serial1.available())
    {
        char c = Serial1.read();
        if (c == '\n' || c == '\r')
        {
            if (xy1Len > 0)
            {
                xy1Buf[xy1Len] = '\0';
                float t = extractTemperature(String(xy1Buf));
                if (!isnan(t))
                {
                    XyRecord rec;
                    rec.type = REC_XYT01_1;
                    rec.timestamp_us = nowUs;
                    rec.sequence = globalSequence++;
                    rec.temperature = t;
                    writeRecord(&rec, sizeof(rec));
                    downlinkUpdateXy1(t);
                }
                xy1Len = 0;
            }
        }
        else if (c >= 32 && c <= 126 && xy1Len < sizeof(xy1Buf) - 1)
        {
            xy1Buf[xy1Len++] = c;
        }
        else
        {
            xy1Len = 0;
        }
    }

    while (Serial2.available())
    {
        char c = Serial2.read();
        if (c == '\n' || c == '\r')
        {
            if (xy2Len > 0)
            {
                xy2Buf[xy2Len] = '\0';
                float t = extractTemperature(String(xy2Buf));
                if (!isnan(t))
                {
                    XyRecord rec;
                    rec.type = REC_XYT01_2;
                    rec.timestamp_us = nowUs;
                    rec.sequence = globalSequence++;
                    rec.temperature = t;
                    writeRecord(&rec, sizeof(rec));
                    downlinkUpdateXy2(t);
                }
                xy2Len = 0;
            }
        }
        else if (c >= 32 && c <= 126 && xy2Len < sizeof(xy2Buf) - 1)
        {
            xy2Buf[xy2Len++] = c;
        }
        else
        {
            xy2Len = 0;
        }
    }
}
